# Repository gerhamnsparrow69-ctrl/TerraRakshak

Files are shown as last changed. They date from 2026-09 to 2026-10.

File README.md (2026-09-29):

# TerraRakshak
TerraRakshak: an AI-assisted 4WD mine rescue rover for SIH 2026 (SIH26039). Three-tier modular design with a 12V drivetrain, a 6-sensor MQ gas array, thermal and night-vision perception, and RPLIDAR SLAM, all integrated on a Raspberry Pi 5 running ROS 2. Team MineCrafters.
TerraRakshak is a modular rover that enters underground mines ahead of rescue teams to report toxic gases, heat signatures and terrain in real time. Built by Team MineCrafters (Team ID 152475) for Smart India Hackathon 2026, problem statement SIH26039.

Architecture

Tier 1, power and drivetrain: 12V LiPo, 2x BTS7960 drivers, 4 encoders and an Arduino Nano, with isolated 12V and 5V buses.
Tier 2, gas array: MQ-2, MQ-4, MQ-7, MQ-8, MQ-135 and MQ-136 sensors on an Arduino Nano, powered through a star topology.
Tier 3, compute and vision: Raspberry Pi 5 as the ROS 2 master, an ESP32 with 4x MLX90640 thermal arrays, 4x night-vision cameras, an RPLIDAR A1M8 and a DHT22.

Repo contents: mechanical design (chassis, machining, assembly sequence), electrical wiring and GPIO maps, and software.

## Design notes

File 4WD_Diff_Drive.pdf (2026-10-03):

SIH 2026 · Team MineCrafters (ID 152475) · Mine Rescue Rover · 4WD drivetrain (Part 4) · all dimensions in mm | Page 1

# Mine Rescue Rover · 4WD Drivetrain (under the base plate)

Four identical corner units (mirrored left/right): wheel -> machined hex drive adaptor -> 10 mm steel stub axle -> 3D-printed bearing flange (2 bearings) -> 3D-printed coupler -> 36 mm planetary gear motor with a built-in rear hall encoder, held in a 3D-printed U-bracket. Axles run parallel to the 30 cm side on Y = 90 (front) and Y = 310 (rear). The two motors of each side run in parallel on one BTS7960 driver (skid steer). The encoders feed the Tier 1 Nano (sheet 8), which closes the speed loop and sends wheel odometry to the Pi 5 alongside the LIDAR SLAM. Every dimension below comes from one model that is checked by script (sheet 6: 0 failures).

## Power

The rover carries three batteries: the 12 V LiPo (motors, through the two BTS7960 drivers), Battery B 5 V (Tier 1 Nano, the four encoders and the driver logic, plus the Tier 2 and Tier 3 logic) and Battery C 5 V (Raspberry Pi 5 and USB hub only, Part 2 sheet C). Battery C feeds nothing in the drivetrain, so the drivetrain sheets and the Tier 1 wiring sheet show only the 12 V LiPo and Battery B.

# Design summary

# | Item | Specification | Reason

1 | Motor | NFP-36GP-555-EN 12 V 27:1, 220 rpm no-load, 12.5 kg·cm rated, 8 mm D-shaft; 17 PPR AB hall encoder built into the motor rear. Body 104.5 (gearbox 34.5 + motor 57 + encoder 13) | Encoder in the same housing: wheel odometry and a closed speed loop with no extra parts to mount
2 | Corner layout | Motor face X 38, encoder rear X 142.5: 15 mm between opposite encoders | Two 104.5 motors fit face to face across the 300 mm plate with room for the encoder plugs
3 | Bearing flange | Top plate 45 (X -15 to 30); web and boss 15 mm outside the plate edge; 2 gussets 30 x 54.5 under the plate; bolts at X 8 / 22 | Carries the wheel load into 4 bolts; puts the bearings outboard so the motors fit
4 | Axle stack | Rod 47 = 15 adaptor / 1 shim / 15 bearings / 1 shim / 15 coupler | 15 mm engagement each side; shims keep spinning parts off the printed flange
5 | Motor mount | U-bracket cradle + clamp cap hold the motor along 60 mm | No cantilever and no holes under the batteries
6 | Wheel | 1/10 MT wheel Ø134.5 x 67, 12 mm hex (2.8" monster-truck set), soft-compound tyre, open-cell foam insert | Axle Z 67.25; lowest point 45.15 (42.15 loaded) for rubble. The tyre squashes ~3 mm and absorbs shock before it reaches the gearbox
7 | Damping | 1.5 mm neoprene pad (60 Shore A) under the flange AND under the bracket lips; both printed 1.5 mm shorter | Damps vibration. Both get a pad so the axle and motor stay exactly coaxial
8 | Fasteners | M4x20 countersunk (DIN 7991), heads flush in the plate top | Nothing pokes up under Battery C, the regulator or the Tier 1 mat
9 | Alignment | Bracket lips have ±5 mm slots; plate holes drilled at the slot centres after alignment | Build independent of small motor tolerances (match-drill)
10 | Cable exits | Ø12 grommets at (150, 115), (150, 285) for the motor leads; Ø10 at (150, 65), (150, 335) for the encoder cables | Keeps the 5 V encoder signals away from the PWM motor leads
11 | Track | Track 431, overall width 498; wheelbase 220, wheelbase/track 0.51 | Easy skid-steer turns and good roll stability on rubble
12 | Odometry | 1836 counts per wheel turn (4.55 counts/mm); per-side speed loop, stall cut-out, slip and encoder-fault detection (sheet 8) | Straight driving under uneven load, protection for gearboxes and printed parts, better SLAM

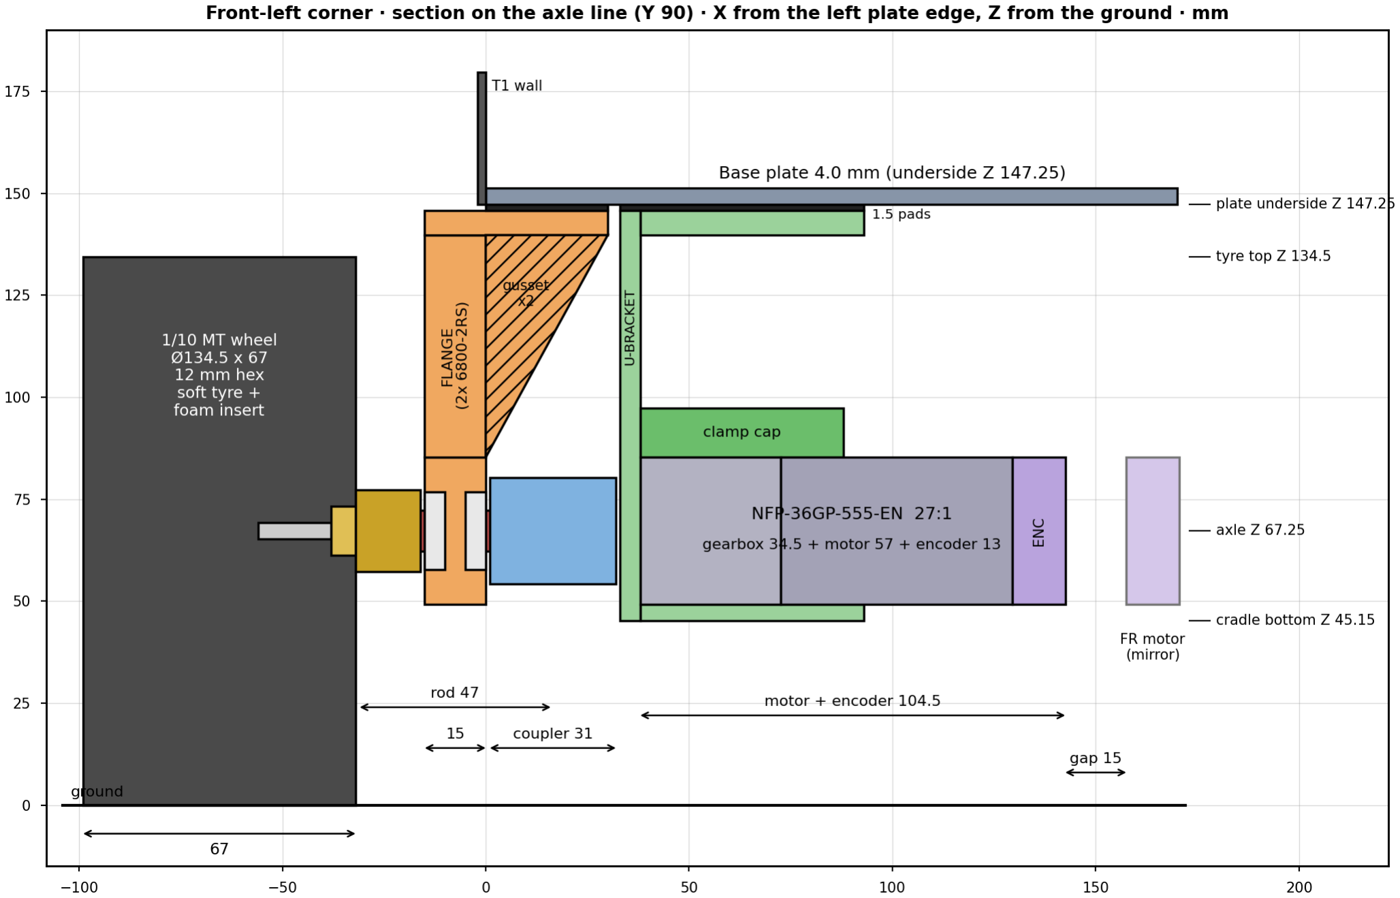
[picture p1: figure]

SIH 2026 · Team MineCrafters (ID 152475) · Mine Rescue Rover · 4WD drivetrain (Part 4) · all dimensions in mm | Page 2

# Sheet 1 · Corner geometry

Part | X from - to (left corner; right = 300 - X) | Z / section
Wheel (tyre) | -99.0 to -32.0 | Ø134.5 x 67, centre Z 67.25, top Z 134.5 (12.75 below the plate)
Hex adaptor | stud -56 to -38 · hex -38 to -32 · collar -32 to -16 | collar Ø20, hex 12 A/F
Shim (outer) | -16 to -15 | 10 x 14 x 1 steel shim, rides on the bearing inner race
Flange boss | -15 to 0 (15 outside the plate; inner face flush with the plate edge) | Ø36, 2 x 6800-2RS
Flange top plate | -15 to 30, Y ±30 about the axle; bolts X 8 / 22 | 6 thick, Z 139.75-145.75; pad X 0-30 only, Z 145.75-147.25
Flange gussets (2) | 0 to 30 (under the plate) | 5 thick at Y ±10 to ±15 about the axle, Z 85.25-139.75
Shim (inner) | 0 to 1
Stub axle | -31 to 16 | Ø10 x 47
Coupler | 1 to 32 | Ø26
U-bracket front wall | 33 to 38 | shaft hole Ø14
U-bracket cradle / lips | 33 to 93 | lips Y ±23.1 to ±43.1 about the axle, Z 139.75-145.75, pad above
Gearbox / can / encoder | 38 to 72.5 / 72.5 to 129.5 / 129.5 to 142.5 | Ø36, Z 49.25-85.25
Clamp cap | 38 to 88 | Z 85.35-97.35
Gap to the opposite motor | 142.5 to 157.5 | 15 mm: room for the encoder plugs (sheet 5, step 5)

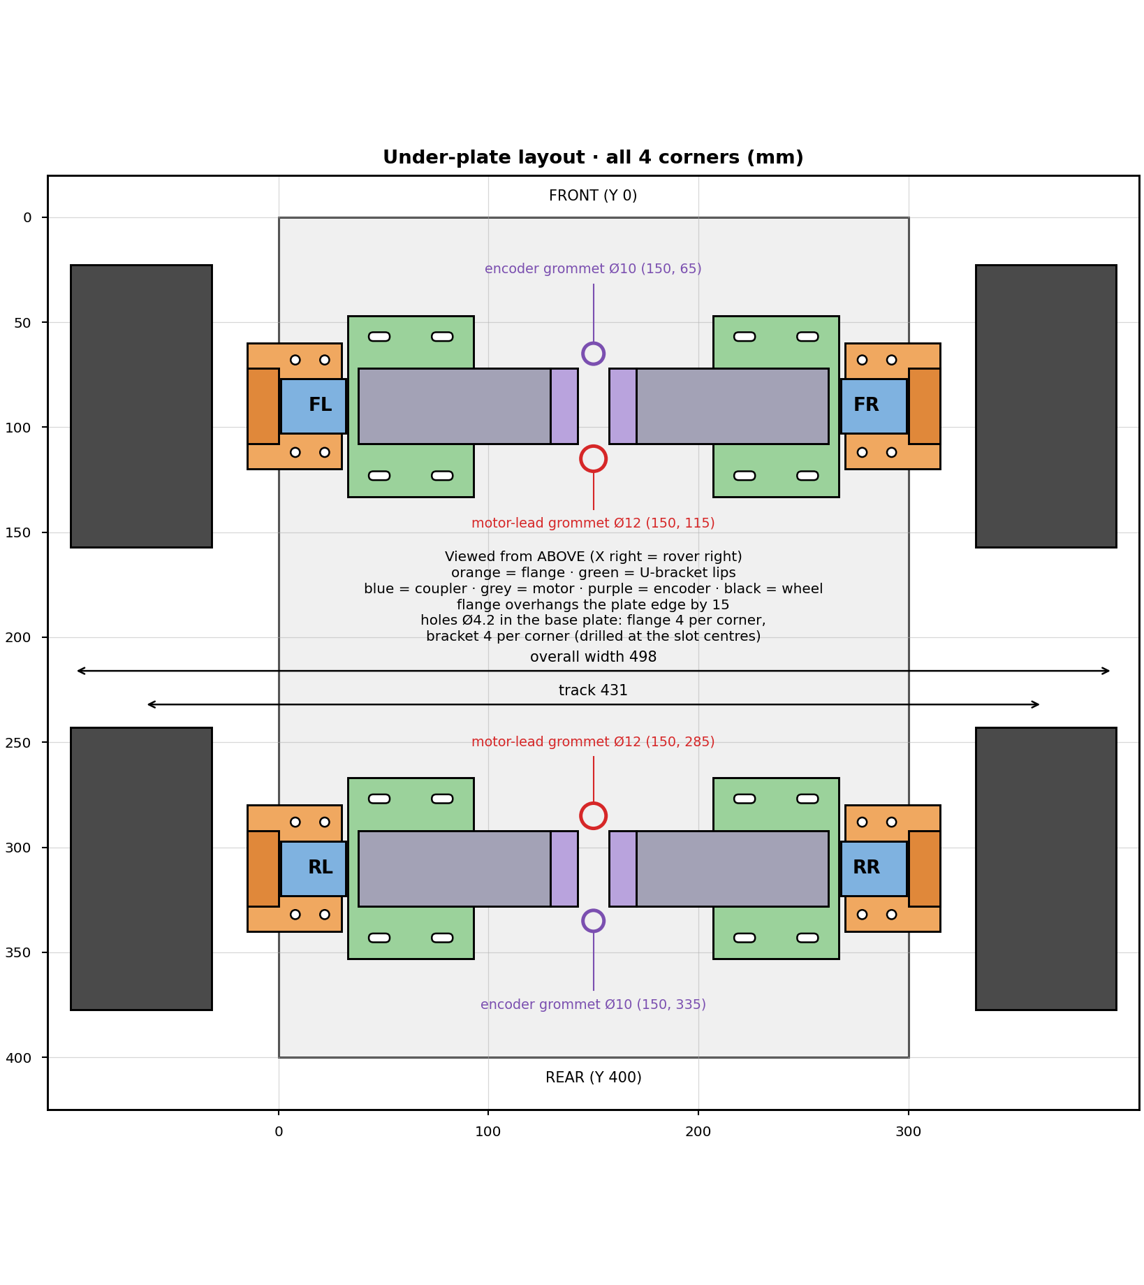
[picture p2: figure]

SIH 2026 · Team MineCrafters (ID 152475) · Mine Rescue Rover · 4WD drivetrain (Part 4) · all dimensions in mm | Page 3

# Sheet 2 · Under-plate layout

Base plate holes per corner (left front shown; right X -> 300 - X, rear Y -> 400 - Y): flange 4 x Ø4.2 with 90° countersink to Ø8.5 on the TOP face, at X 8 and 22, Y 68 and 112. Bracket 4 x Ø4.2 (same countersink) at the slot centres, nominal X 48 and 78, Y 56.9 and 123.1, drilled after the alignment step (sheet 5, step 6). Grommets: Ø12 at (150, 115) and (150, 285) for the motor leads; Ø10 at (150,
65) and (150, 335) for the encoder cables.

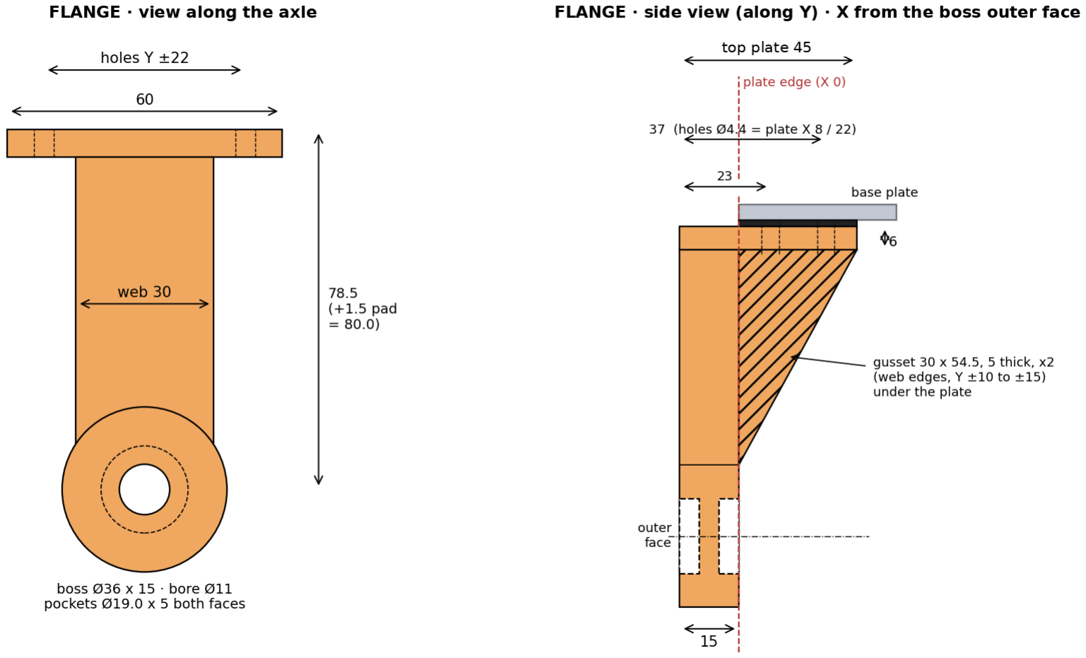
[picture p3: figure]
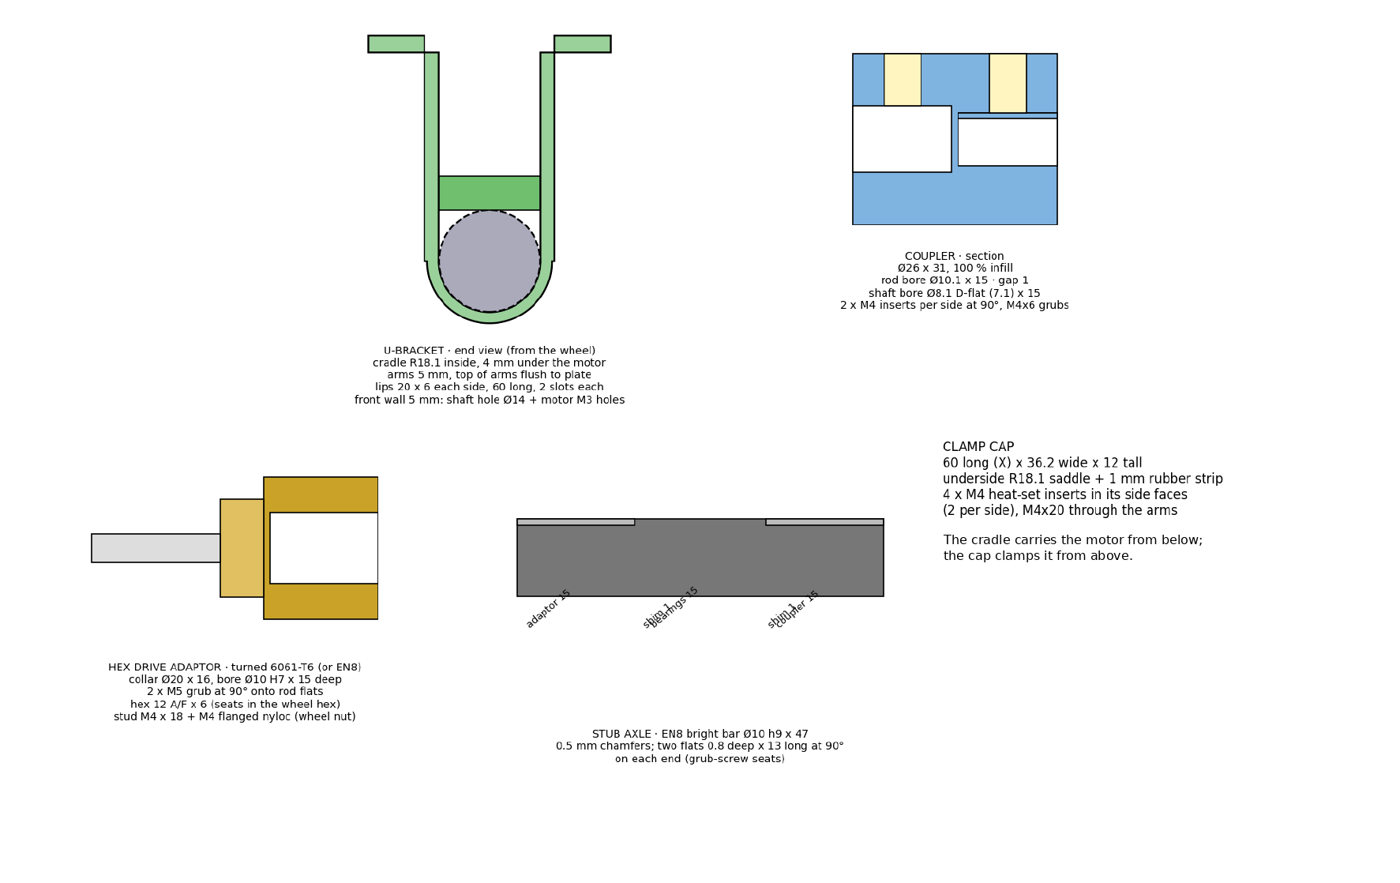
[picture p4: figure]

SIH 2026 · Team MineCrafters (ID 152475) · Mine Rescue Rover · 4WD drivetrain (Part 4) · all dimensions in mm | Page 4

# Sheet 3 · Parts

Printed: flange, U-bracket, clamp cap and coupler (4 of each). Machined: stub axle and hex drive adaptor (4 of each). The flange top plate is 45 long so the web and boss hang 15 mm outside the plate edge; the two gussets sit under the plate and carry the overhang into the bolts.

## U-bracket, coupler, clamp cap, hex drive adaptor and stub axle

## 3D-printing settings

Part | Qty | Material | Orientation on the bed | Settings
Flange | 4 | PETG (upgrade: PA6-CF or PETG-CF, hardened nozzle) | Outer boss face down: web, boss and gussets print as in-plane layers, bearing pockets print as true circles; the 45 mm top plate stands vertical | 0.4 nozzle, 0.2 layer, 6 walls, 6 top / 6 bottom, 60 % gyroid, 240 °C / bed 80 °C, supports only under the top-plate bolt holes. About 60 g each
U-bracket | 4 | same | Front wall down: every layer is the full U profile, so arm bending stays in-plane | same, 60 % gyroid, slots printed
Clamp cap | 4 | same | Flat top down | 5 walls, 40 % gyroid; press 4 M4 heat-set inserts after printing
Coupler | 4 | PETG or PA6-CF | Axis vertical, rod bore up | 100 % infill (rectilinear), 0.15 layer; 4 M4 heat-set inserts
Test ring | 1 | same | flat | Print a Ø19.0 pocket ring first: the bearing must press in by hand-vise. If loose, retain with Loctite 641 (or thin CA)

Printed holes are drawn at 4.4 mm (not 4.2) because printed holes shrink about 0.2 mm; drill to 4.2-4.4 if tight. Metal plate holes stay 4.2 mm.

SIH 2026 · Team MineCrafters (ID 152475) · Mine Rescue Rover · 4WD drivetrain (Part 4) · all dimensions in mm | Page 5

# Sheet 4 · Procurement (for 4 corners)

Item | Exact part | Qty | Note
Motor | NFP-36GP-555-EN 12 V, 27:1 (gearbox 34.5 mm), built-in 17 PPR AB hall encoder, XH2.54 6-pin cable, Ø8 D-shaft. Same size alternative: CHIHAI CHP-36GP-555-ABHLL 27:1 | 4 | About US$43 each. Ask for the outline drawing: body (gearbox face to encoder cover) must be 104.5 (max 106). Shaft extension 17-21 mm; cut to 21 if longer. Match-drill the M3 face holes
Wheels | 1/10 MT 2.8" wheel + tyre, 12 mm hex, Ø134.5 x 67, pre-glued, e.g. Jetko Rockform JK2803CB (ships with 12 / 14 / 17 mm hexes) | 4 | Fit the 12 mm hex. Soft compound with an open-cell foam insert; no closed-cell or dual-stage hard inserts. Check the M4 wheel stud takes the full nyloc through the hub
Bearings | 6800-2RS, 10 x 19 x 5 | 8 | 2 per flange
Stub axles | EN8 (or C45) bright bar Ø10 h9, cut to 47 | 4 | Mill or file the grub flats (sheet 3)
Hex adaptors | Turned to the sheet 3 drawing, 6061-T6 or EN8 | 4 | Any local lathe shop; bore Ø10 H7
Pads | Neoprene (CR) sheet 1.5 mm, 60 Shore A | 4 + 8 | 60 x 30 under each flange, 60 x 20 under each bracket lip; holes Ø4.5
Shims | 10 x 14 x 1 steel shim washers | 8
Bolts | M4 x 20 countersunk DIN 7991 + 1 mm rubber washers + M4 nyloc | 32 sets | 16 flange + 16 bracket lip, heads flush with the plate top
Cap bolts | M4 x 20 socket head | 16 | Into the cap inserts, no nut
Heat-set inserts | M4, 5.6-5.7 mm OD, 8 mm long (cap) / 6.4 mm (coupler) | 16 + 16
Grub screws | M4 x 6 (coupler) · M5 x 6 (adaptor), cup point | 16 · 8 | Loctite 243
Wheel nuts | M4 flanged nyloc | 4
Motor screws | M3, length = bracket wall 5 + thread depth in gearbox (usually 3-4) -> M3 x 8 | 16-24
Grommets | Rubber, 12 mm hole | 2 | Motor leads, (150, 115) and (150, 285)
Grommets | Rubber, 10 mm hole | 2 | Encoder cables, (150, 65) and (150, 335)
Encoder wiring | 4-core 24 AWG flexible cable (or 4 twisted wires) + JST XH2.54 6-pin pigtail if the motor cable is short; Dupont or screw terminals at the Nano | 4 x ~50 cm | Heat-shrink every joint; label FL / RL / FR / RR at both ends
Filament | PETG (or PA6-CF / PETG-CF) | ~1 kg | All printed parts and the test ring

SIH 2026 · Team MineCrafters (ID 152475) · Mine Rescue Rover · 4WD drivetrain (Part 4) · all dimensions in mm | Page 6

# Sheet 5 · Assembly (base plate upside down on the bench)

## 1 · Prepare

Print the flanges, U-brackets, clamp caps, couplers and the test ring. Press the heat-set inserts. Cut and flat the axles. Deburr. Drill the flange holes and the four grommet holes in the base plate (sheet 2); leave the bracket holes for step 6.

## 2 · Flanges

Press two 6800-2RS into each flange (one per face, flush). Lay the 1.5 mm pad (60 x 30) where the top plate meets the base plate (X 0-30), then bolt: countersunk head flush in the plate top, plate, pad, flange, rubber washer, nyloc. Tighten until the pad just starts to bulge (do not crush it). The boss hangs outside the plate: its inner face is flush with the plate edge, the outer face is 15 mm out.

## 3 · Axles

Slide the outer shim, then the axle through the bearings from outside, so 15 mm protrudes outboard beyond the shim and 16 mm inboard. Fit the inner shim.

## 4 · Couplers

Push the coupler rod bore fully onto the inner 15 mm of the axle, against the inner shim (the shims should turn freely, with no end play). Tighten both grubs onto the flats (Loctite 243).

## 5 · Motors and encoder socket

Find the encoder socket on the motor rear. Radial socket: turn the motor so it points toward the nearest plate end (front motors to the front, rear motors to the rear), i.e. toward the encoder grommet. Axial socket (on the back face): left motors socket at 12 o'clock, right motors at 6 o'clock, so the two plugs in the 15 mm gap never face each other. The M3 face holes are match-drilled, so any rotation works. Then screw the face to the U-bracket wall (M3), lay the motor in the cradle with the rubber strip, fit the clamp cap and its 4 bolts.

## 6 · Align and drill (match-drill)

Slide the motor shaft into the coupler until the bracket lips sit flat on the plate and the wall is 1 mm from the coupler end. Mark the plate through the 4 slot centres (nominal X 48 / 78), remove the motor, drill Ø4.2 and countersink the top, then refit with the lip pads and bolt (same stack and pad squeeze as the flange). Tighten the coupler shaft grubs onto the D-flat. Turn the wheel end by hand: it must turn with no binding.

## 7 · Wheels

Fit the 12 mm hex in each wheel (the set also ships 14 and 17 mm hexes). Slide the hex adaptor onto the outer 15 mm (against the outer shim), tighten both M5 grubs onto the flats (Loctite 243), fit the wheel onto the hex and tighten the M4 flanged nyloc.

## 8 · Wiring

Motor leads up through the Ø12 grommets: FL + RL to the LEFT driver M+ / M-, FR + RR to the RIGHT driver (Part 1). Encoder cables up through the Ø10 grommets to the Tier 1 Nano (sheet 8). If the motor's 6-pin plug also carries M+ / M-, split it at the motor: those two go to the driver on 18 AWG, only the four encoder wires go to the Nano. Zip-tie the cables to the lips, clear of the tyres. Do not swap M+ / M- to fix direction: the bring-up check stores the signs in the Nano.

## 9 · Check

On the floor the tyres squash about 3 mm; lowest point (cradle) about 42.2 mm; 15 mm between opposite encoder covers. Then run the bring-up check (sheet 8, step 3) with the wheels off the ground.

SIH 2026 · Team MineCrafters (ID 152475) · Mine Rescue Rover · 4WD drivetrain (Part 4) · all dimensions in mm | Page 7

# Sheet 6 · Verification

| Check (script: drivetrain_model.py)
OK | Flange/bracket drop plate-underside to axle = 80.0 mm (spec 80.0)
OK | Axle height = tyre radius = 67.25 mm
OK | Tyre top 134.5, plate underside 147.25 -> clearance 12.75 mm
OK | Rod 47 mm = adaptor 15 + shim 1 + bearings 15 + shim 1 + coupler 15
OK | Coupler end 32.0, bracket wall starts 33.0 (gap 1.0)
OK | Motor shaft engagement in coupler 15.0 mm (min 12)
OK | Coupler clears flange boss (shim 1.0 mm between)
OK | Motor body = gearbox 34.5 + can 57 + encoder 13 = 104.5 mm
OK | Left motor rear 142.5, right motor rear 157.5 -> gap 15.0 mm (>= 12 for an axial encoder socket)
OK | Flange top plate ends X 30, bracket lips start X 33 (gap 3.0)
OK | Flange top plate X -15 to 30: 15 mm overhang past the plate edge, bolts stay at X 8 / 22
OK | Gussets (under the plate) clear the coupler top Z 80.25 by >= 6.8 mm
OK | Gusset ends X 30, U-bracket wall starts X 33 (gap 3.0)
OK | With 3 mm soft-tyre squash under load: lowest point 42.15 mm
OK | Lowest point (bracket cradle) 45.15 mm above ground; motor + encoder 49.25; flange boss 49.25
OK | Tyre inner face at X -32.0 -> 17.0 mm to the flange boss, 32 mm outside the plate edge
OK | Track (tyre centre to centre) 431 mm, overall width 498 mm
OK | Tyres along Y: front 22.75-157.25, rear 242.75-377.25 -> inside the plate length, 85.5 mm apart
OK | M4x20 countersunk flange (CSK flush) + 1.5 pad: plate 4 + pad 1.5 + part 6 + rubber washer 1 + nyloc 5 -> 2.5 mm past nut
OK | M4x20 countersunk bracket lip (CSK flush) + 1.5 pad: plate 4 + pad 1.5 + part 6 + rubber washer 1 + nyloc 5 -> 2.5 mm past nut
OK | Pads: flange and bracket lips both on 1.5 mm pads, both printed 1.5 mm shorter -> axle and motor coaxial at 80.0 below the plate
OK | M4x20 arm into cap insert: 14.2 mm of thread in the cap
OK | Under-plate footprints: flange top, bracket lips, 4 grommets - no overlaps
OK | Encoder grommet (150, 65): its edge is 2 mm off the motor side in plan and 62 mm above the motor top
OK | Motor cantilever past the cradle: 49.5 mm, carried by the clamp cap
OK | Encoder: 17 PPR x 27:1 x 4 = 1836 counts per wheel turn = 4.55 counts/mm (loaded tyre Ø128.5)
OK | Worst-case edge rate, 4 motors at no-load 220 rpm: 26.9 k interrupts/s (~5 µs each -> 13 % of the Nano)
| TOTAL FAILURES: 0

## Confirm on the real parts

# | Check

1 | Motor shaft extension (face to tip) is 17-21 mm; cut to 21 if longer. With 21 the coupler takes 15 mm of shaft.
2 | Motor body length (gearbox face to the back of the encoder cover, socket not included) is 104.5, at most 106. Above 106 the gap between opposite motors drops below 12 mm. Measure one motor before printing the flanges.
3 | Encoder socket: if it is axial, plug + wire bend must stick out 11 mm or less from the cover (sheet 5, step 5 staggers the plugs).
4 | Encoder pinout from the motor label / datasheet: which wires are M+, M-, GND, VCC, A, B. VCC takes 3.3-5 V only, never 12 V.
5 | Chassis doc: nothing hangs under the plate where the bracket lips sit (X 33-93 and 207-267, Y 46.9-133.1 and 266.9-353.1), in particular no lower-T1-bracket nut or bolt tip, and nothing hangs below the plate edge at the flange overhang (X -15 to 0).
6 | Tier 1 layout above: the Ø10 holes at (150, 65) and (150, 335) and the bracket holes at X 48 / 78 are clear of everything on the plate top (standoffs, pillars, battery bays).
7 | Wheel: 12 mm hex seat; the tyre inner face ends up 32 mm outside the plate edge, and the M4 stud still takes the full nyloc through the wheel hub.
8 | Bearing pocket press fit on the test ring before printing all four flanges.
9 | After fitting the pads, the axle and motor turn freely by hand; if the coupler binds, the two pads are squeezed unequally.

SIH 2026 · Team MineCrafters (ID 152475) · Mine Rescue Rover · 4WD drivetrain (Part 4) · all dimensions in mm | Page 8

# Sheet 7 · Insulation mat (chassis, all decks)

A mat on every enclosed deck floor keeps loose wires, solder joints and bolt tips off the aluminium. It goes inside each deck only, not on the exposed ledges of the lower roofs and not on the top roof.

Item | Specification
Material | Silicone rubber sheet, 1.5 mm, 50 Shore A, flame-retardant grade (UL94 V-0), rated to 200 °C. Silicone survives the heat near the BTS7960 heatsinks and does not melt onto the plate
Tier 1 | 30.0 x 40.0 cm on the base plate
Tier 2 | 22.0 x 35.0 cm on the mid plate, inside the Tier 2 box
Tier 3 | 18.1 x 31.1 cm on the Tier 2 roof, inside the Tier 3 box
Cut-outs (+1 mm all round) | Pillars, every lip / lower bracket, latch posts and the wire pass-through holes: brackets must clamp metal to metal, never on the mat. This includes Ø14 cut-outs around the four drivetrain grommets at (150, 65), (150, 115), (150, 285) and (150, 335)
Cut-outs under breadboards | All 400-pt and 170-pt breadboards stick straight onto the aluminium (their adhesive will not hold on silicone). This keeps the MQ and MLX90640 heights, so the gas ports (4.40 cm) and thermal arches (3.5 cm) still line up
Holes | Punch Ø5 for every bolt and standoff that passes through the floor (drivers, bus bars, Pi 5, hub, battery bays)
Fixing | Held down by the parts bolted through it; add a few dots of neutral-cure RTV silicone at the corners
Height effect | Parts sitting on the mat rise 1.5 mm. The tallest (Tier 1 drivers, 4.5 cm) become 4.65 cm, still 2.8 cm below the nearest bolt tip hanging from the mid plate (7.42 cm). All drivetrain bolt heads are countersunk flush, so nothing pushes up under the mat

Quantity: one 50 x 50 cm sheet covers Tier 1; one more sheet covers Tier 2 and Tier 3.

SIH 2026 · Team MineCrafters (ID 152475) · Mine Rescue Rover · 4WD drivetrain (Part 4) · all dimensions in mm | Page 9

# Sheet 8 · Encoders and the Tier 1 Nano

Each motor carries a 2-channel hall encoder: 17 pulses per motor turn on A and B, 90° apart. Through the 27:1 gearbox with x4 decoding that is 1836 counts per wheel turn, 4.55 counts per mm (loaded tyre Ø128.5). The Tier 1 Nano counts all four, runs a 50 Hz speed loop per side (the two motors of a side share one BTS7960) and streams the counts to the Pi 5 at 25 Hz. Worst case (all four at 220 rpm no-load) is 26.9 k edges/s, well inside the Nano's interrupt budget.

## Encoder cable (per motor)

Encoder wire | Goes to | Note
VCC | Tier 1 5 V rail (Battery B) | 3.3-5 V only. The encoder has its own pull-ups, so A / B swing 0-5 V
GND | Tier 1 GND trunk | No extra link to the 12 V side (one common GND link rule, Part 2 sheet C)
A, B | Nano pins in the table below | Keep these 4 wires together, away from the motor leads
M+, M- (if on the plug) | BTS7960 M+ / M- of that side, 18 AWG | Split at the motor, through the Ø12 grommet (sheet 5, step 8)

Only two of the rover's three batteries reach Tier 1 drivetrain circuits: the 12 V LiPo (driver B+ / B-) and Battery B (5 V rail). Battery C feeds only the Pi 5 and the USB hub (Part 2 sheet C).

## Tier 1 Nano pin map

Nano pin | Connects to | Why
D9 / D10 | LEFT BTS7960 RPWM / LPWM | Timer1 PWM, 3.92 kHz (driver limit 25 kHz)
D8 | LEFT BTS7960 R_EN + L_EN (tied) | HIGH = enabled; LOW while booting
D3 / D11 | RIGHT BTS7960 RPWM / LPWM | Timer2 PWM, same 3.92 kHz
D12 | RIGHT BTS7960 R_EN + L_EN (tied)
D4 / D5 | FL encoder A / B | Port D pin-change interrupt (fixed pins)
D6 / D7 | RL encoder A / B | Port D pin-change interrupt (fixed pins)
A0 / A1 | FR encoder A / B | Port C pin-change interrupt (fixed pins)
A2 / A3 | RR encoder A / B | Port C pin-change interrupt (fixed pins)
D13 | on-board LED | slow blink running · solid waiting for the Pi · fast blink fault
5V / GND | Tier 1 5 V rail: both drivers' VCC / GND and the 4 encoders' VCC / GND | Part 2 sheet C
USB (D0 / D1) | Pi 5 through the hub | 115200 baud; free pins: D2, A4, A5, A6, A7
Driver pins match the Part 1 wiring sheet. Driver pins can be changed in the constants at the top of the sketch (PWM must stay on D3 / D9 / D10 / D11). The encoder pins are fixed: the interrupt code reads whole ports. BTS7960 R_IS / L_IS stay unconnected; stalls are detected from the encoders.

## Link to the Pi 5 (full description in the sketch header)

Direction | Message | Meaning
Pi -> Nano | V,left,right | wheel speed per side, mm/s (±1000), closed loop
| P,left,right | open-loop PWM (±255), bring-up only
| S · R · I · D | brake · zero counters, clear faults · identify · dump config
| C,fl,rl,fr,rr,ml,mr · K,kp,ki,kff | signs (±1) · gains x1000, both saved in EEPROM
Nano -> Pi | E,ms,fl,rl,fr,rr,vl,vr,pl,pr,flags,errs* HH | 25 Hz: cumulative counts, side speeds, PWM, flags (stall, slip, encoder fault, watchdog), missed edges
| I,TIER1_DRIVE,4B,1.0 · A,x · N,reason | identity (at boot) · ack · reject

SIH 2026 · Team MineCrafters (ID 152475) · Mine Rescue Rover · 4WD drivetrain (Part 4) · all dimensions in mm | Page 10

## Built-in protection

Situation | What the Nano does
No command for 300 ms | Both sides ramp to 0 and brake (watchdog flag)
Stall: PWM ≥ 140 with the side below 15 mm/s for 0.7 s | That side is braked and latched until the Pi commands 0 for it (after 1 s) or sends R. Protects gearboxes, printed couplers and the 20 A fuse
Any speed change | Setpoint ramp 1200 mm/s²
One encoder dead (its partner turns, it does not) | Flag for that wheel; the side keeps running on the other wheel's encoder
Front and rear of one side differ (> 100 mm/s or 30 %) | Slip flag; the ROS 2 node widens the odometry covariance

## Bring-up and calibration

Step | Do this
1 | Flash tier1_drive_nano/tier1_drive_nano.ino (Arduino IDE, board Arduino Nano, ATmega328P; pick 'Old Bootloader' if the upload times out). The LED stays on: waiting for the Pi.
2 | On the Pi 5: python3 -m pip install pyserial, then ls /dev/serial/by-id/ to find the Tier 1 Nano (the Tier 2 Nano and the ESP32 are on USB too; always use the by-id path).
3 | Rover on blocks, wheels off the ground, 12 V on: python3 rover_base.py --port <path> --check. It spins each side slowly, asks whether the wheels turned forward, and stores the motor and encoder signs in the Nano. A reversed side is fixed in software.
4 | On the floor: --calib-distance 1000 (tape measure), then --calib-turn (one turn in place). Results go to ~/.config/rover_base.json. Skid steer usually calibrates to an effective track larger than 431.
5 | --monitor shows counts, speeds and flags. For the SLAM stack: python3 rover_base_ros2.py --ros-args -p port:=<path> (/cmd_vel in; /odom and the odom -> base_link TF out).

Simulation test (simulated Nano with motor, quadrature and driver models, driven by the Pi code): sign detection on deliberately mis-wired hardware, 300 mm/s tracking, straight and turning odometry, stall latch and release, slip, dead-encoder fallback, watchdog and config storage all passed. Final gains are tuned on the real rover with --gains.

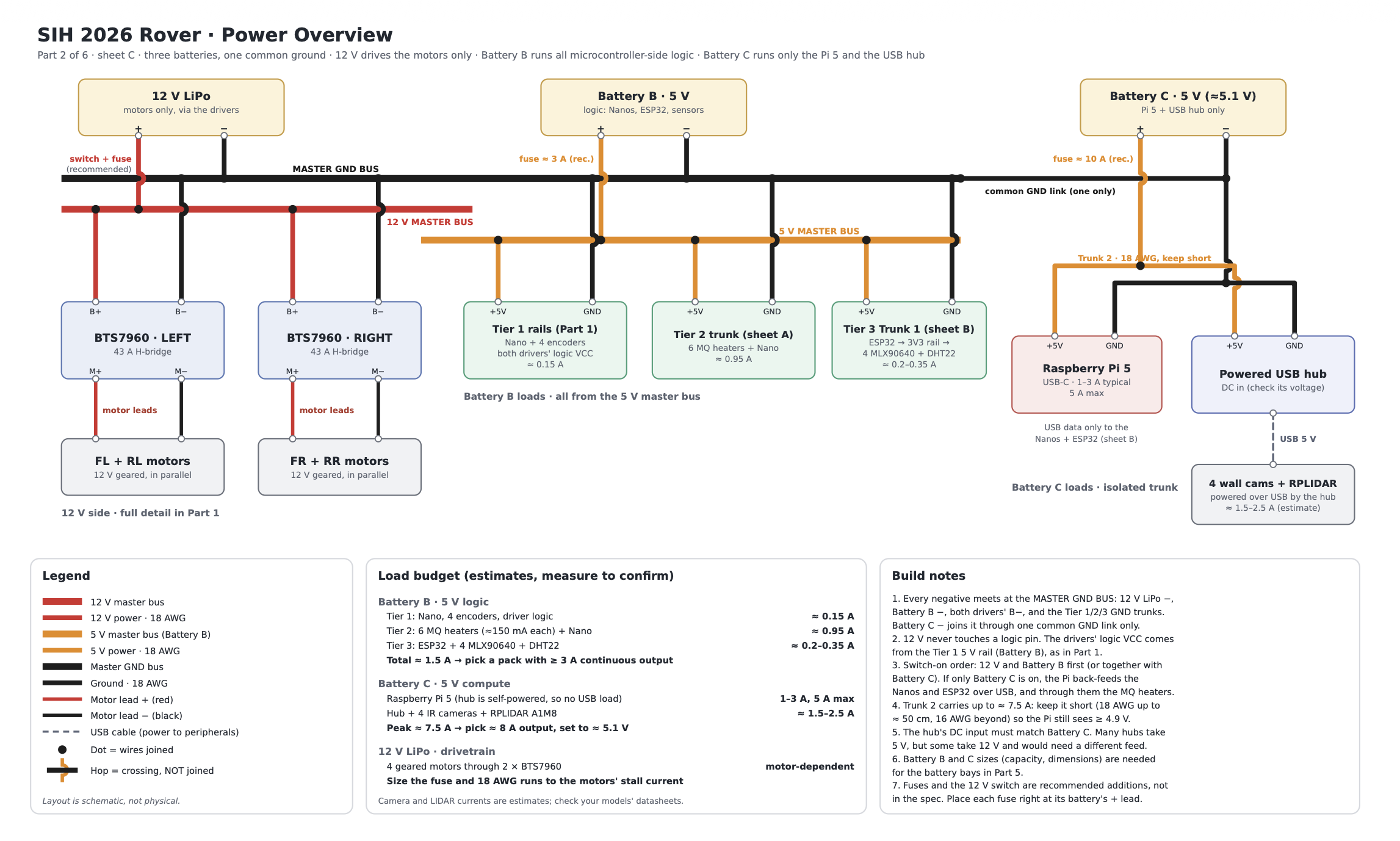
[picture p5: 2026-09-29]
Wiring/Power_overview.png

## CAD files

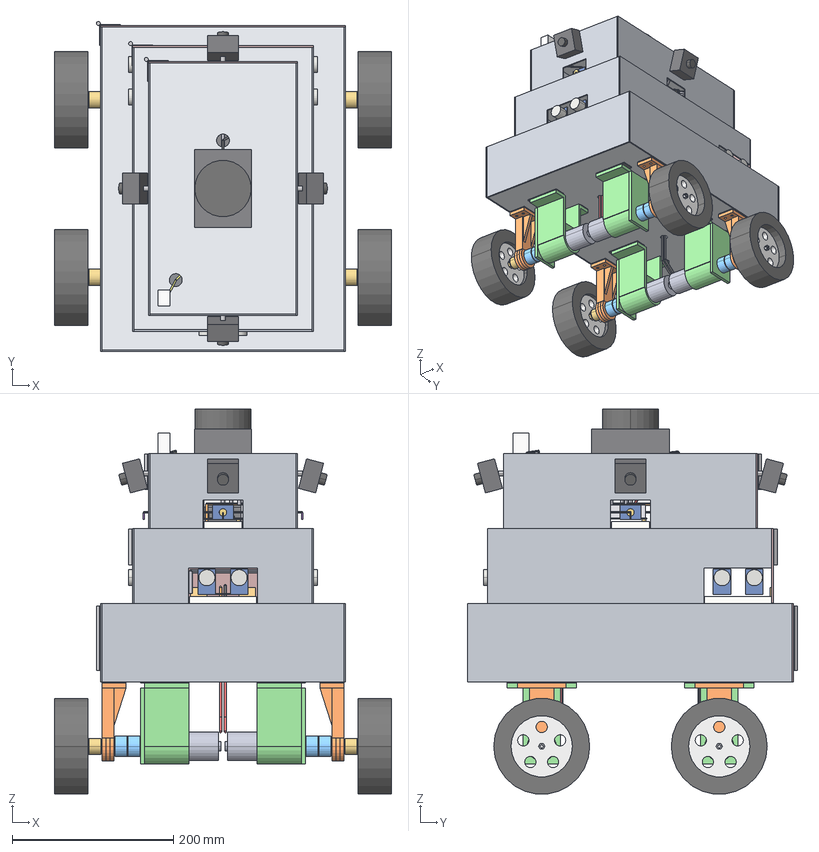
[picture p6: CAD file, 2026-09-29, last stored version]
SIH2026_Rover_Full_Assembly.step
418.0 x 409.0 x 477.1 mm
Base_Plate_4mm
Mid_Plate_3mm
Tier2_Roof_3mm
Roof_3mm
T1_Wall_Left
T1_Wall_Right
T1_Wall_Front
T1_Door_Rear
T2_Wall_Left
T2_Wall_Right
T2_Wall_Front
T2_Door_Rear
T3_Wall_Left
T3_Wall_Right
T3_Wall_Front
T3_Door_Rear
T1_Door_Hinge
T2_Door_Hinge
T3_Door_Hinge
T1_Corner_Pillars
T2_Latch_Post
T3_Latch_Post
T1_L_Brackets
T2_L_Brackets
T3_L_Brackets
T1_Silicone_Mat
T2_Silicone_Mat
T3_Silicone_Mat
Battery_12V_LiPo
Battery_B_Logic_5V
Battery_C_Pi_5V
Regulator_5V1_8A
Driver1_BTS7960
Driver2_BTS7960
Bus_12V
Bus_5V
Bus_GND
T1_Breadboard
T1_Arduino_Nano
T2_Board_Front
T2_Board_Centre
T2_Board_Left
T2_Board_Right
T2_Arduino_Nano
MQ_2
MQ_4
MQ_7
MQ_8
MQ_135
MQ_136
T3_Mini_Front
T3_Mini_Rear
T3_Mini_Left
T3_Mini_Right
T3_Breadboard_ESP32
ESP32_DevKit
MLX90640_Front
MLX90640_Rear
MLX90640_Left
MLX90640_Right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

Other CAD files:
SIH2026_Rover_Full_Assembly.f3d

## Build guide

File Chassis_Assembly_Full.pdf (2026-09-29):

SIH 2026 · Team MineCrafters (ID 152475) · Mine Rescue Rover · Chassis & electronics assembly (Part 3) · all dimensions in cm unless marked | Page 1

# Mine Rescue Rover · Chassis, Enclosures & Electronics Assembly

Tier 1 skeleton, Tier 2 gas deck, Tier 3 compute deck, roof, walls, doors, fasteners and component placement. The 4WD drivetrain under the base plate is a separate document (next part). Every placement in this document comes from one coordinate model that is checked by script for clashes, fit and bolt length (results on the last page: 0 errors).

# Key design decisions

# | Design adopted | Why

1 | M4x20 everywhere structural; stack: head · metal washer 0.8 mm · plate · bracket · 1.0 mm rubber washer · M4 nyloc (5.0 mm) | Lengths checked per joint (sheet 3)
2 | Walls outside every plate, zero gap. Bracket outer faces flush with the plate edge; plate sizes unchanged | Deck dimensions never change
3 | Walls cover the plate edges: Tier 1 = 9.7 (0.4 + 9.0 + 0.3), Tier 2/3 = 9.3 (9.0 + 0.3) | Full 9.0 cm clear height inside every tier
4 | Pillars tapped 20 mm (drill 3.3 mm to 23 mm). M4x20 through the 4 mm base engages 15.2 mm of thread | A 15 mm tap depth would bottom out and the bolt would not clamp
5 | Drill 4.2 mm clean through the pillar, washer + nyloc inside (stack 18.6 mm, 1.4 mm past nut). Side-wall holes Z 3.0/6.0, end-face holes Z 3.5/6.5 so they never cross | An M4x20 cannot be threaded into a 10 mm pillar side
6 | Rear wall of each tier = hinged access door: piano hinge at rear-left, 2 M4x20 latch bolts at rear-right (Tier 1 into the RR pillar, Tier 2/3 into a 45 mm latch post). Rear brackets stay as door stops | Hand access for lip bolts; no nuts needed inside a closed box
7 | Gas ports 8.5 x 4.40 cm, open at the bottom: MQ modules stand vertical (32 mm PCB) and their domes face out. Open bottom lets the box drop over the jutting sensors | Vertical sensors are 4.30 cm tall
8 | MLX90640 110° stands on its header facing the wall (a flat board looks at the ceiling). Arches 4.9 x 3.5 cm; left/right minis at Y 13.2-17.9 so all 4 lenses sit on the arch centres | Unclipped 110°x70° view; 4 x 110° = full 360° coverage
9 | Camera holes Z 6.80 | A camera at 5.75 would hang into the thermal sensor's upper field of view
10 | Battery C bay beside the 12 V bus (X 2.3-9.5, Y 2.3-15.5) + 5.1 V regulator bay (X 21.0-27.0, Y 11.0-15.5) | Pi 5 + hub isolated from logic power
11 | Real A1M8 envelope 7.03 x 9.68 x 5.5 at dead centre | Datasheet size

SIH 2026 · Team MineCrafters (ID 152475) · Mine Rescue Rover · Chassis & electronics assembly (Part 3) · all dimensions in cm unless marked | Page 2

# Sheet 1 · Components and exact sizes used

Item | Model chosen | Size used in the model (cm) | Notes
Gas sensors x6 | MQ-2/4/7/8/135/136 FC-22 style modules | PCB 3.2 x 2.2, envelope 3.2 x 2.2 x 2.7, dome Ø2.0 | Published module size 32x22x27 mm. Standing vertical on the 4-pin header
Thermal x4 | Adafruit MLX90640 4469 (110° x 70°) | 2.58 x 1.78 x 1.05 | Wide version chosen for maximum coverage; 3.3-5 V supply, runs on ESP32 3V3
400-pt breadboards x5 | standard | 8.2 x 5.5 x 0.85 | Fixed with their adhesive backing (no holes exist for standoffs)
170-pt minis x4 | standard | 4.7 x 3.5 x 0.85
USB hub | Waveshare USB-HUB-7U | reserved bay 11.8 x 7.5 x 3.0 | 7 x USB 2.0, MTT, DC 5 V terminal input only (matches Battery C), metal case with mounting holes. Check its outline drawing (Waveshare wiki, image only) against the bay before buying.
Battery C (Pi + hub) | 2S 7.4 V LiPo + 5.1 V step-down | bay 7.2 x 13.2 x 4.5; regulator bay 6.0 x 4.5 x 2.5 | Pack: 2S, 3000-4000 mAh, >=20C, case <= 13.0 x 7.0 x 4.5. Regulator: 5.1 V out, >=8 A continuous (Pi 5 up to ~5 A + hub 1.5-2.5 A). Pick a pack by its datasheet case size, not the listing photo
Raspberry Pi 5 | 8 GB | 8.5 x 5.6, 3.0 tall on 1.0 standoffs | M2.5 holes 58 x 49 mm, 3.5 mm from edges
RPLIDAR | Slamtec A1M8 | 9.68 x 7.03 x 5.5 | Mount through its own base holes; match-drill the roof from the unit
DHT22 | 3-pin module | 1.5 x 2.0 footprint, 2.51 tall | Roof front-left
Brackets | 20 x 20 x 2 mm aluminium angle, 20 mm wide | 2.0 x 2.0 x 2.0 | One Ø4.2 hole per leg at 11 mm from the corner
Pillars / latch posts | 10 x 10 mm solid aluminium | 1 x 1 x 9.0 / 1 x 1 x 4.5 | Tapped M4 20 mm deep at bolted ends
Hinge | aluminium piano hinge, 50 mm open (2 x 25 mm leaves) | cut to 8.0 (T1) / 4.4 (T2, T3) long | Knuckle on the outside rear-left corner

# Sheet 2 · Plate and wall cut list

Part | Qty | Size (cm) | Material | Machining
Base plate (Tier 1 floor) | 1 | 30.0 x 40.0 | 4.0 mm Al | 12 lower-bracket holes, 4 pillar holes (under pillars, bolt up), driver/bus/battery fixings, drivetrain pattern (separate doc)
Mid plate (T1 roof / T2 floor) | 1 | 30.0 x 40.0 | 3.0 mm Al | 12 upper-bracket + 4 pillar holes, 8 Tier-2 lip holes, hinge-side clearance, H-T2 Ø16 at (15.0, 26.2), H-T3 Ø25 at (22.0, 25.7)
Tier 2 roof (T3 floor) | 1 | 22.0 x 35.0 | 3.0 mm Al | 8 roof-bracket holes, latch-post hole, 8 Tier-3 lip holes, H-T3 Ø25 at T2-local (18.0, 23.2)
Roof | 1 | 18.1 x 31.1 | 3.0 mm Al | 8 roof-bracket holes, latch-post hole, H-DHT22 Ø16 at (3.2, 4.2), H-LIDAR Ø16 at (9.05, 21.5), LIDAR holes match-drilled
T1 left / right side walls | 2 | 40.2 x 9.7 | 2.0 mm Al | Front end overlaps front wall; rear end flush with plate edge (door covers it)
T1 front wall | 1 | 30.0 x 9.7 | 2.0 mm Al | Sits between the side walls
T1 rear door | 1 | 30.4 x 9.7 | 2.0 mm Al | Covers side-wall ends
T2 side walls | 2 | 35.2 x 9.3 | 2.0 mm Al | MQ ports Y 26.6-35.0 x 0-4.40
T2 front wall | 1 | 22.0 x 9.3 | 2.0 mm Al | MQ port X 6.75-15.25 x 0-4.40
T2 rear door | 1 | 22.4 x 9.25 | 2.0 mm Al | Solid; 0.5 mm above the floor so it swings
T3 side walls | 2 | 31.3 x 9.3 | 2.0 mm Al | Arch Y 13.1-18.0 x 0-3.5, camera hole (15.55, Z 6.8)
T3 front wall | 1 | 18.1 x 9.3 | 2.0 mm Al | Arch X 6.6-11.5 x 0-3.5, camera hole (9.05, Z 6.8)
T3 rear door | 1 | 18.5 x 9.25 | 2.0 mm Al | Arch + camera hole as front (shifted +0.2 by the overlap)
Pillars | 4 | 1 x 1 x 9.0 | 10 mm Al bar | Ends tapped M4 x 20 deep; 2 through-holes per outer face (see #5)
Latch posts | 2 | 1 x 1 x 4.5 | 10 mm Al bar | Top tapped 20 deep; door taps (Y) at Z 4.9 and 6.5; side through-hole (X) at Z 5.7
L-brackets | 24 (T1) + 16 (T2) + 16 (T3) | 20 x 20 x 20 mm | 2.0 mm Al | T1 12 lower + 12 upper; T2/T3 8 lips + 8 roof brackets each (2 per wall)

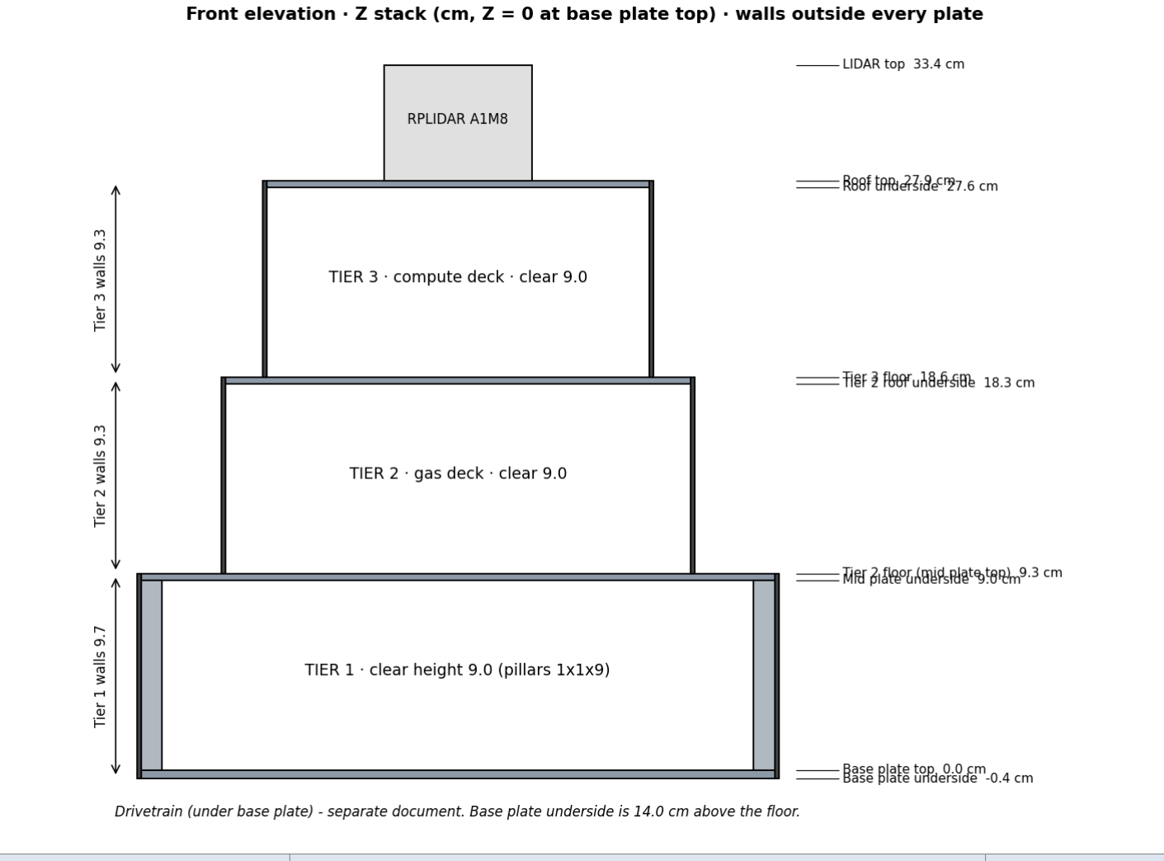
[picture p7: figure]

SIH 2026 · Team MineCrafters (ID 152475) · Mine Rescue Rover · Chassis & electronics assembly (Part 3) · all dimensions in cm unless marked | Page 3

# Sheet 3 · Heights and fasteners

Joint | Stack (mm) | Past the nyloc
Bracket to 3.0 mm plate | washer 0.8 + plate 3.0 + bracket 2.0 + rubber 1.0 + nyloc 5.0 = 11.8 | 8.2 mm
Bracket to 4.0 mm base plate | 0.8 + 4.0 + 2.0 + 1.0 + 5.0 = 12.8 | 7.2 mm
Wall to bracket leg | 0.8 + wall 2.0 + bracket 2.0 + 1.0 + 5.0 = 10.8 | 9.2 mm (points inward, all checked clear)
Wall to pillar / latch post (through) | 0.8 + 2.0 + 10.0 + washer 0.8 + nyloc 5.0 = 18.6 | 1.4 mm (2 threads, enough for the nylon insert)
Plate into pillar end (tapped) | 0.8 + 4.0 (base) or 3.0 (mid) -> 15.2 / 16.2 mm of thread | tap depth 20 mm, Loctite blue
Door into pillar / post (tapped) | 0.8 + door 2.0 -> 17.2 mm, exits 7.2 mm inside the corner | corner area is clear
Hinge leaf to wall | 0.8 + leaf 1.0 + wall 2.0 + 0.8 + 5.0 = 9.6 | 10.4 mm

Rubber washers go only where a bolt passes an L-bracket (spec 7.2). Every lip bolt tip that hangs into the deck below stops 1.58 cm under that plate; the script confirms nothing sits there.

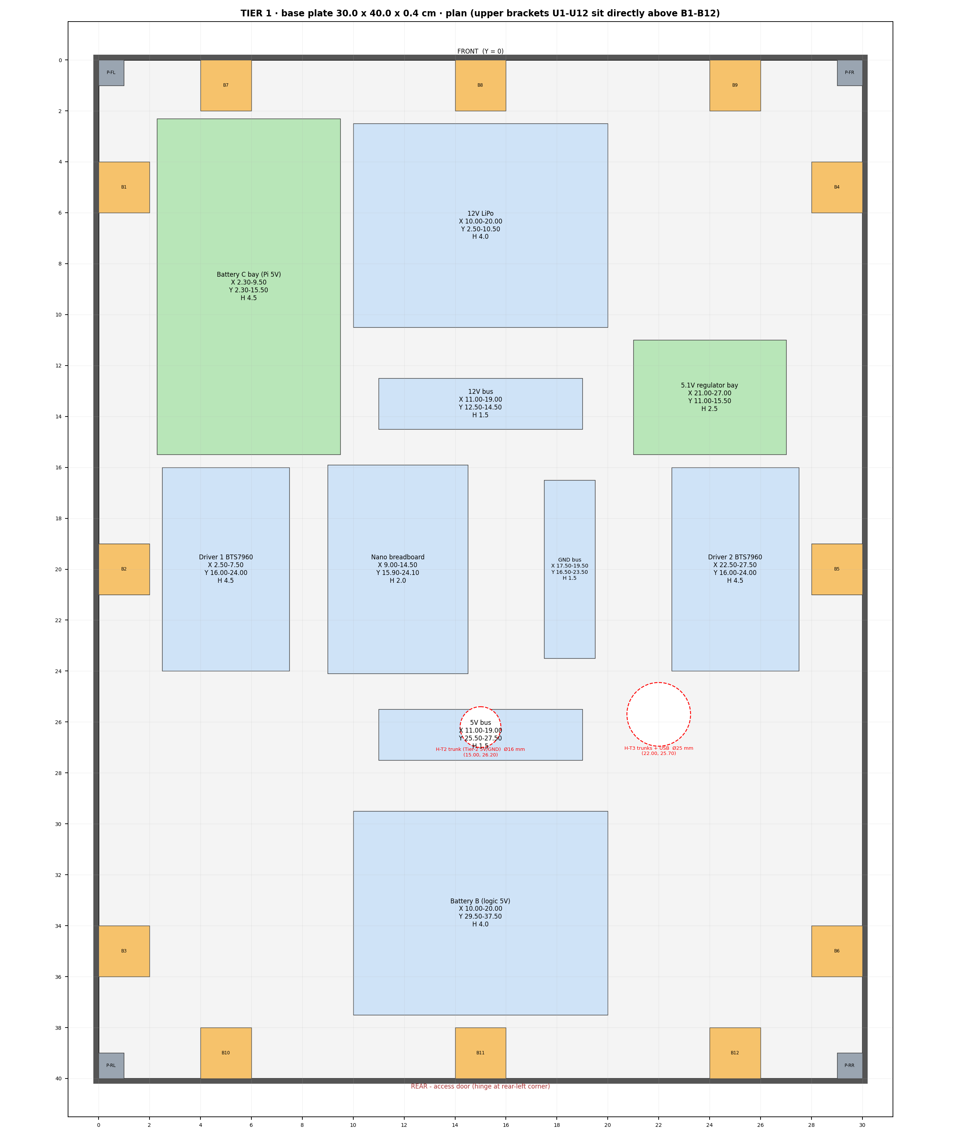
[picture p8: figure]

SIH 2026 · Team MineCrafters (ID 152475) · Mine Rescue Rover · Chassis & electronics assembly (Part 3) · all dimensions in cm unless marked | Page 4

# Sheet 4 · Tier 1 skeleton (base plate)

Dashed red circles are holes in the mid plate above (wire pass-throughs). Upper brackets U1-U12 are directly above B1-B12, bolted to the mid plate. B10-B12 / U10-U12 are door stops (not bolted to the door).

SIH 2026 · Team MineCrafters (ID 152475) · Mine Rescue Rover · Chassis & electronics assembly (Part 3) · all dimensions in cm unless marked | Page 5
Part | X from-to | Y from-to | Height
P-FL | 0.00 - 1.00 | 0.00 - 1.00 | 9.00
P-FR | 29.00 - 30.00 | 0.00 - 1.00 | 9.00
P-RL | 0.00 - 1.00 | 39.00 - 40.00 | 9.00
P-RR | 29.00 - 30.00 | 39.00 - 40.00 | 9.00
12V LiPo | 10.00 - 20.00 | 2.50 - 10.50 | 4.00
12V bus | 11.00 - 19.00 | 12.50 - 14.50 | 1.50
Driver 1 BTS7960 | 2.50 - 7.50 | 16.00 - 24.00 | 4.50
Nano breadboard | 9.00 - 14.50 | 15.90 - 24.10 | 2.00
GND bus | 17.50 - 19.50 | 16.50 - 23.50 | 1.50
Driver 2 BTS7960 | 22.50 - 27.50 | 16.00 - 24.00 | 4.50
5V bus | 11.00 - 19.00 | 25.50 - 27.50 | 1.50
Battery B (logic 5V) | 10.00 - 20.00 | 29.50 - 37.50 | 4.00
Battery C bay (Pi 5V) | 2.30 - 9.50 | 2.30 - 15.50 | 4.50
5.1V regulator bay | 21.00 - 27.00 | 11.00 - 15.50 | 2.50
Bracket | Wall | Centre along wall (cm)
B1 | Left | 5.0
B2 | Left | 20.0
B3 | Left | 35.0
B4 | Right | 5.0
B5 | Right | 20.0
B6 | Right | 35.0
B7 | Front | 5.0
B8 | Front | 15.0
B9 | Front | 25.0
B10 | Rear | 5.0
B11 | Rear | 15.0
B12 | Rear | 25.0

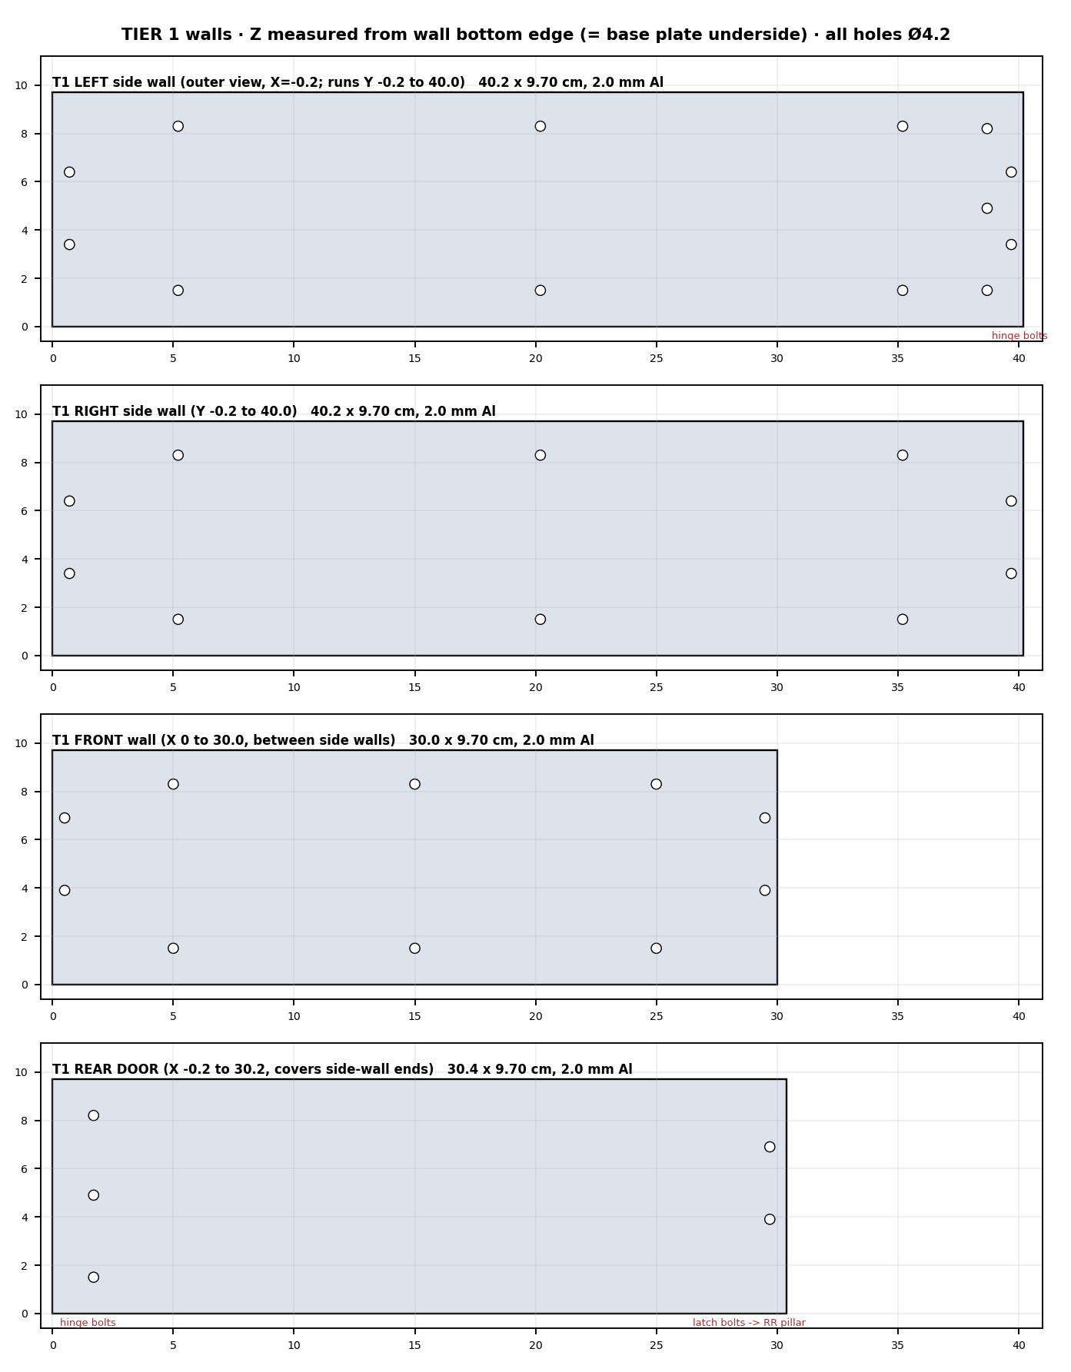
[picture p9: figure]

SIH 2026 · Team MineCrafters (ID 152475) · Mine Rescue Rover · Chassis & electronics assembly (Part 3) · all dimensions in cm unless marked | Page 6

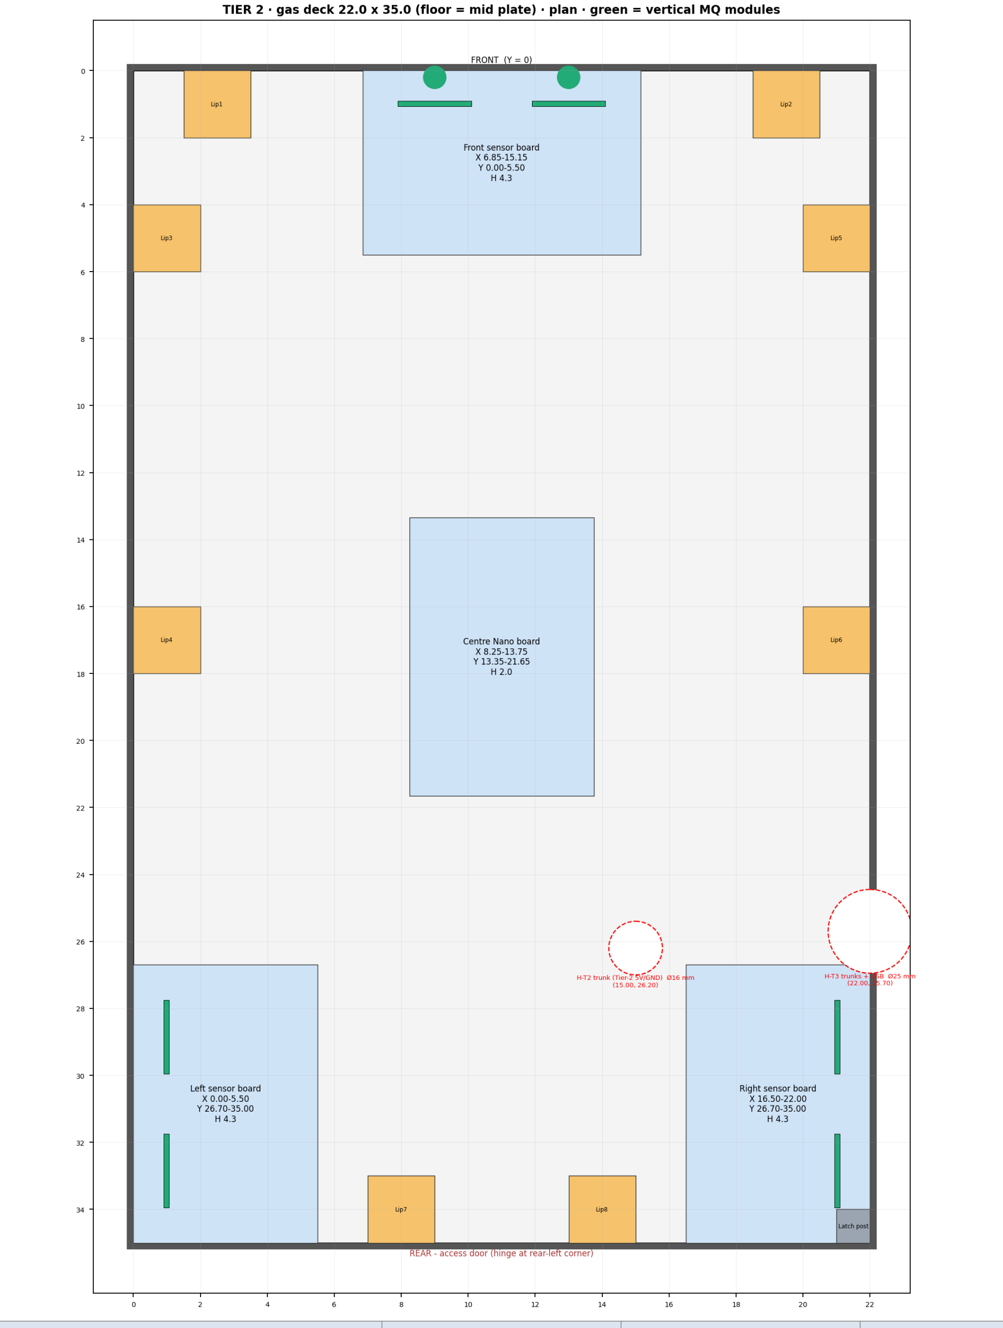
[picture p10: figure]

SIH 2026 · Team MineCrafters (ID 152475) · Mine Rescue Rover · Chassis & electronics assembly (Part 3) · all dimensions in cm unless marked | Page 7

# Sheet 5 · Tier 2 gas deck

Part | X from-to | Y from-to | Height
Front sensor board | 6.85 - 15.15 | 0.00 - 5.50 | 4.30
Centre Nano board | 8.25 - 13.75 | 13.35 - 21.65 | 2.00
Left sensor board | 0.00 - 5.50 | 26.70 - 35.00 | 4.30
Right sensor board | 16.50 - 22.00 | 26.70 - 35.00 | 4.30
Latch post | 21.00 - 22.00 | 34.00 - 35.00 | Z 4.5-9.0
Bracket | Wall | Centre along wall (cm)
Lip1 | Front | 2.5
Lip2 | Front | 19.5
Lip3 | Left | 5.0
Lip4 | Left | 17.0

SIH 2026 · Team MineCrafters (ID 152475) · Mine Rescue Rover · Chassis & electronics assembly (Part 3) · all dimensions in cm unless marked | Page 8
Bracket | Wall | Centre along wall (cm)
Lip5 | Right | 5.0
Lip6 | Right | 17.0
Lip7 | Rear | 8.0
Lip8 | Rear | 14.0

MQ modules: two per board, PCB centres at X 9.0 and 13.0 (front board) and Y 28.85 and 32.85 (side boards), plugged into the breadboard row nearest the wall with the dome facing out. The dome projects about 1.2-1.4 cm past the breadboard edge, so it pushes through the 2 mm wall into the open air. Dry-fit one module first; the open-bottom port tolerates any row.

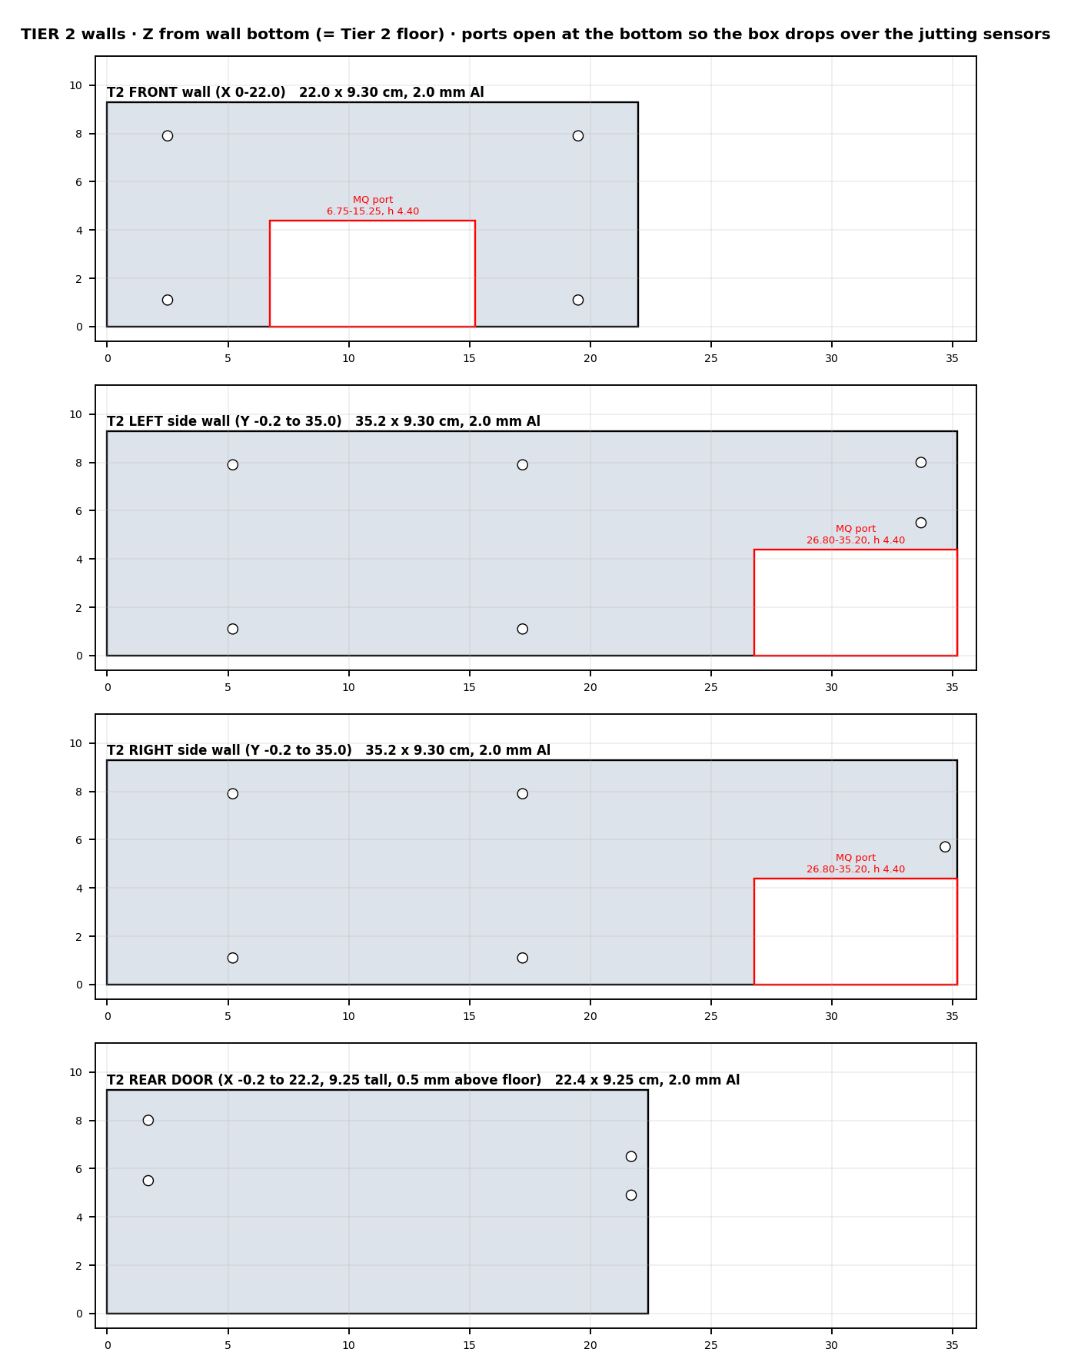
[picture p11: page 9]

SIH 2026 · Team MineCrafters (ID 152475) · Mine Rescue Rover · Chassis & electronics assembly (Part 3) · all dimensions in cm unless marked | Page 9

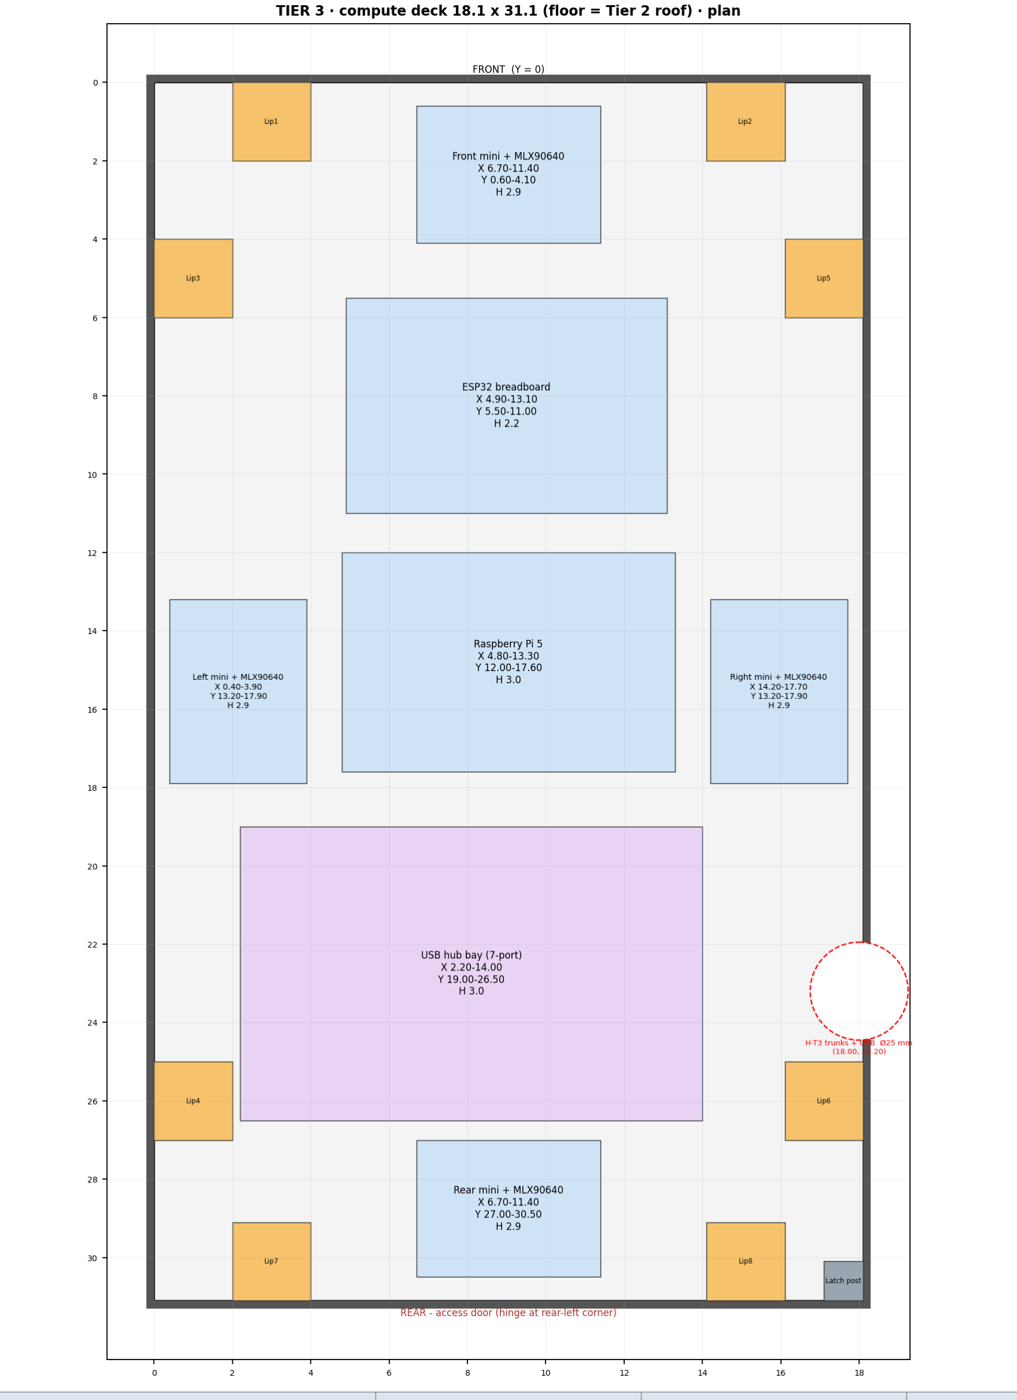
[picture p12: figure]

SIH 2026 · Team MineCrafters (ID 152475) · Mine Rescue Rover · Chassis & electronics assembly (Part 3) · all dimensions in cm unless marked | Page 10

# Sheet 6 · Tier 3 compute deck

Part | X from-to | Y from-to | Height
Front mini + MLX90640 | 6.70 - 11.40 | 0.60 - 4.10 | 2.88
Rear mini + MLX90640 | 6.70 - 11.40 | 27.00 - 30.50 | 2.88
Left mini + MLX90640 | 0.40 - 3.90 | 13.20 - 17.90 | 2.88
Right mini + MLX90640 | 14.20 - 17.70 | 13.20 - 17.90 | 2.88
ESP32 breadboard | 4.90 - 13.10 | 5.50 - 11.00 | 2.20
Raspberry Pi 5 | 4.80 - 13.30 | 12.00 - 17.60 | 3.00
USB hub bay (7-port) | 2.20 - 14.00 | 19.00 - 26.50 | 3.00
Latch post | 17.10 - 18.10 | 30.10 - 31.10 | Z 4.5-9.0
Bracket | Wall | Centre along wall (cm)
Lip1 | Front | 3.0
Lip2 | Front | 15.1
Lip3 | Left | 5.0

SIH 2026 · Team MineCrafters (ID 152475) · Mine Rescue Rover · Chassis & electronics assembly (Part 3) · all dimensions in cm unless marked | Page 11
Bracket | Wall | Centre along wall (cm)
Lip4 | Left | 26.0
Lip5 | Right | 5.0
Lip6 | Right | 26.0
Lip7 | Rear | 3.0
Lip8 | Rear | 15.1

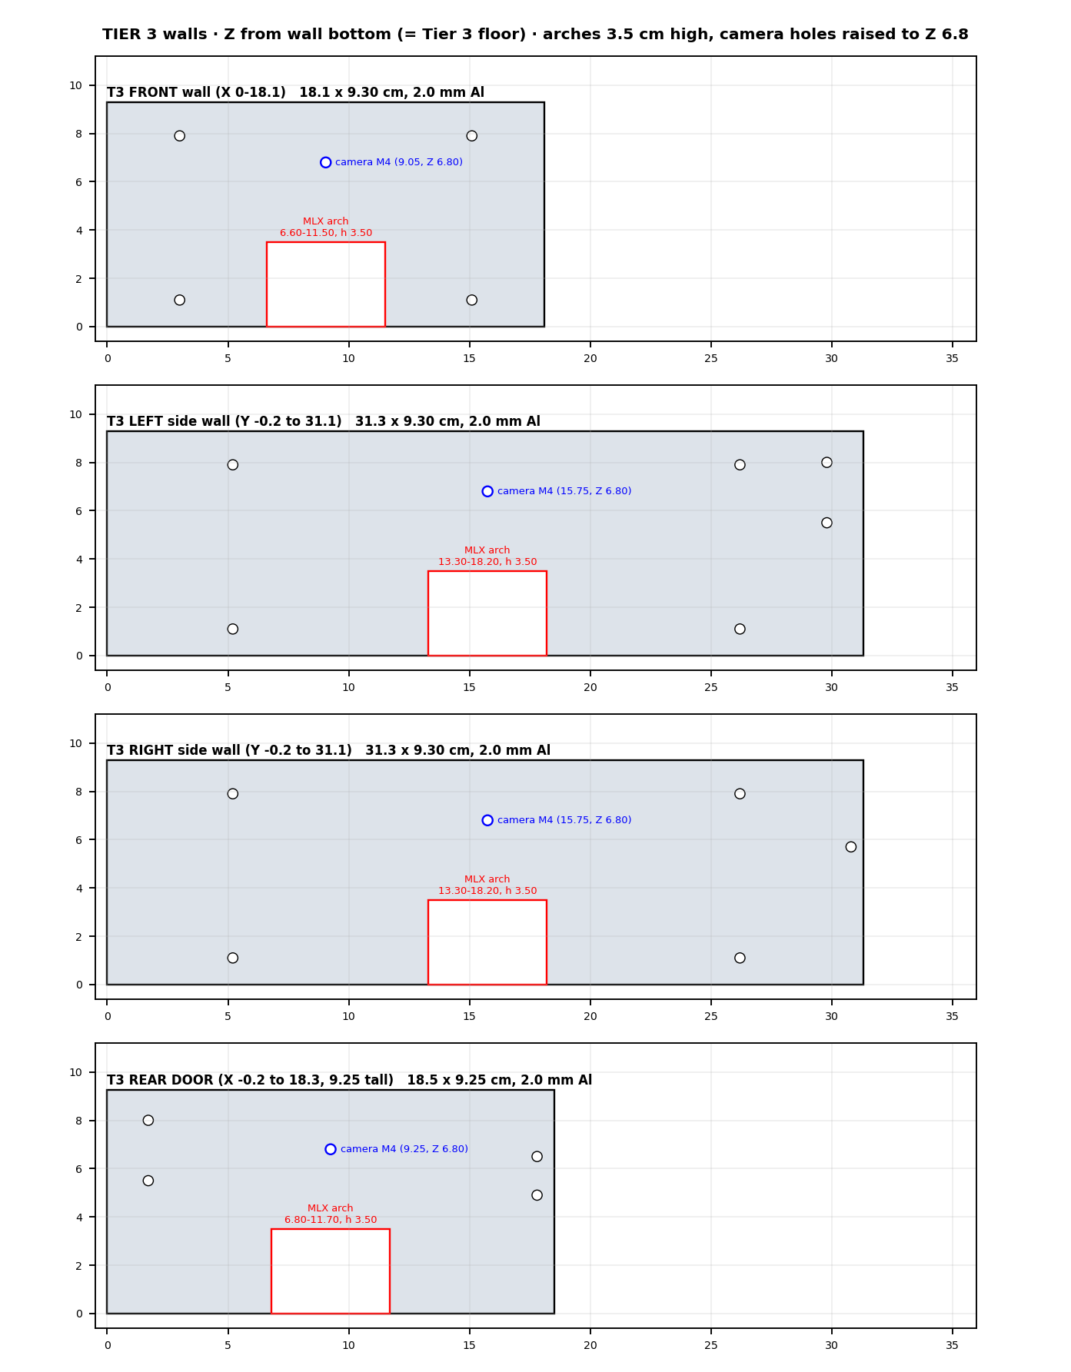
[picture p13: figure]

SIH 2026 · Team MineCrafters (ID 152475) · Mine Rescue Rover · Chassis & electronics assembly (Part 3) · all dimensions in cm unless marked | Page 12

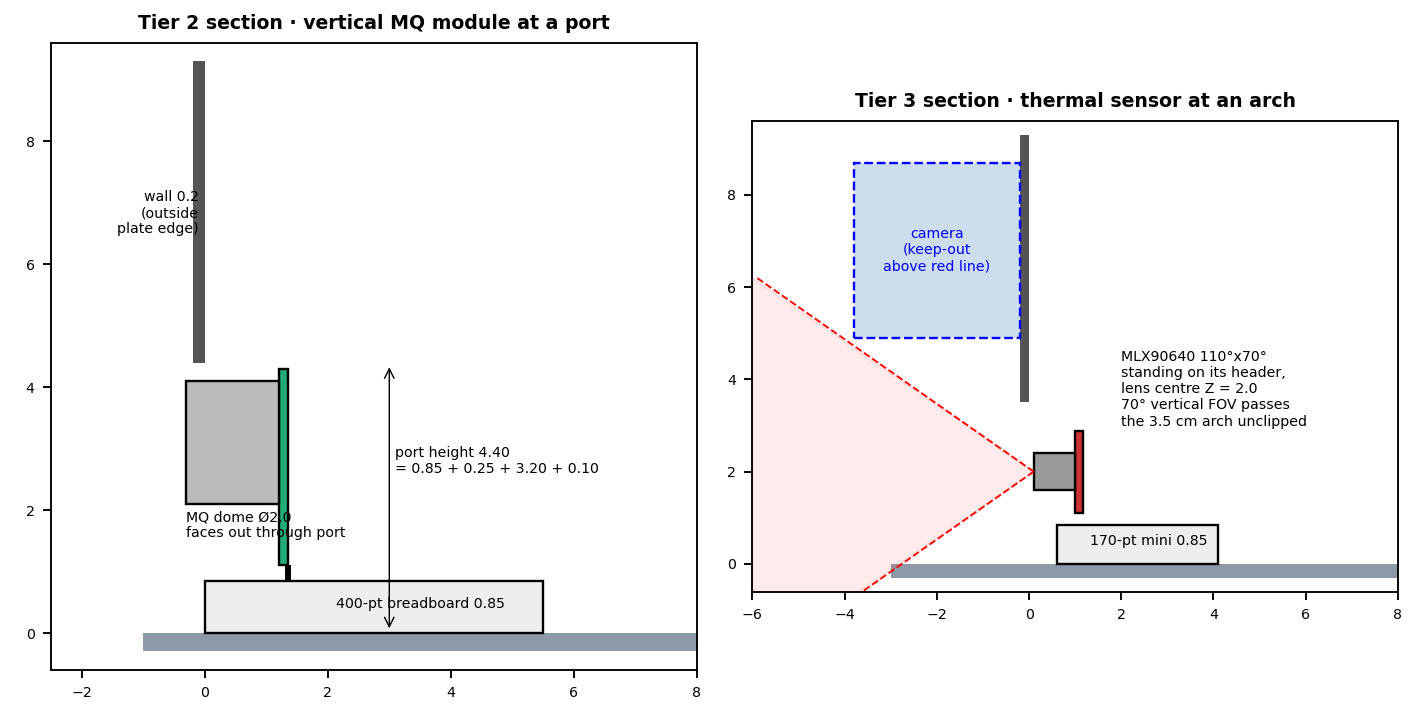
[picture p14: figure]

SIH 2026 · Team MineCrafters (ID 152475) · Mine Rescue Rover · Chassis & electronics assembly (Part 3) · all dimensions in cm unless marked | Page 13

# Sheet 7 · Roof and access doors

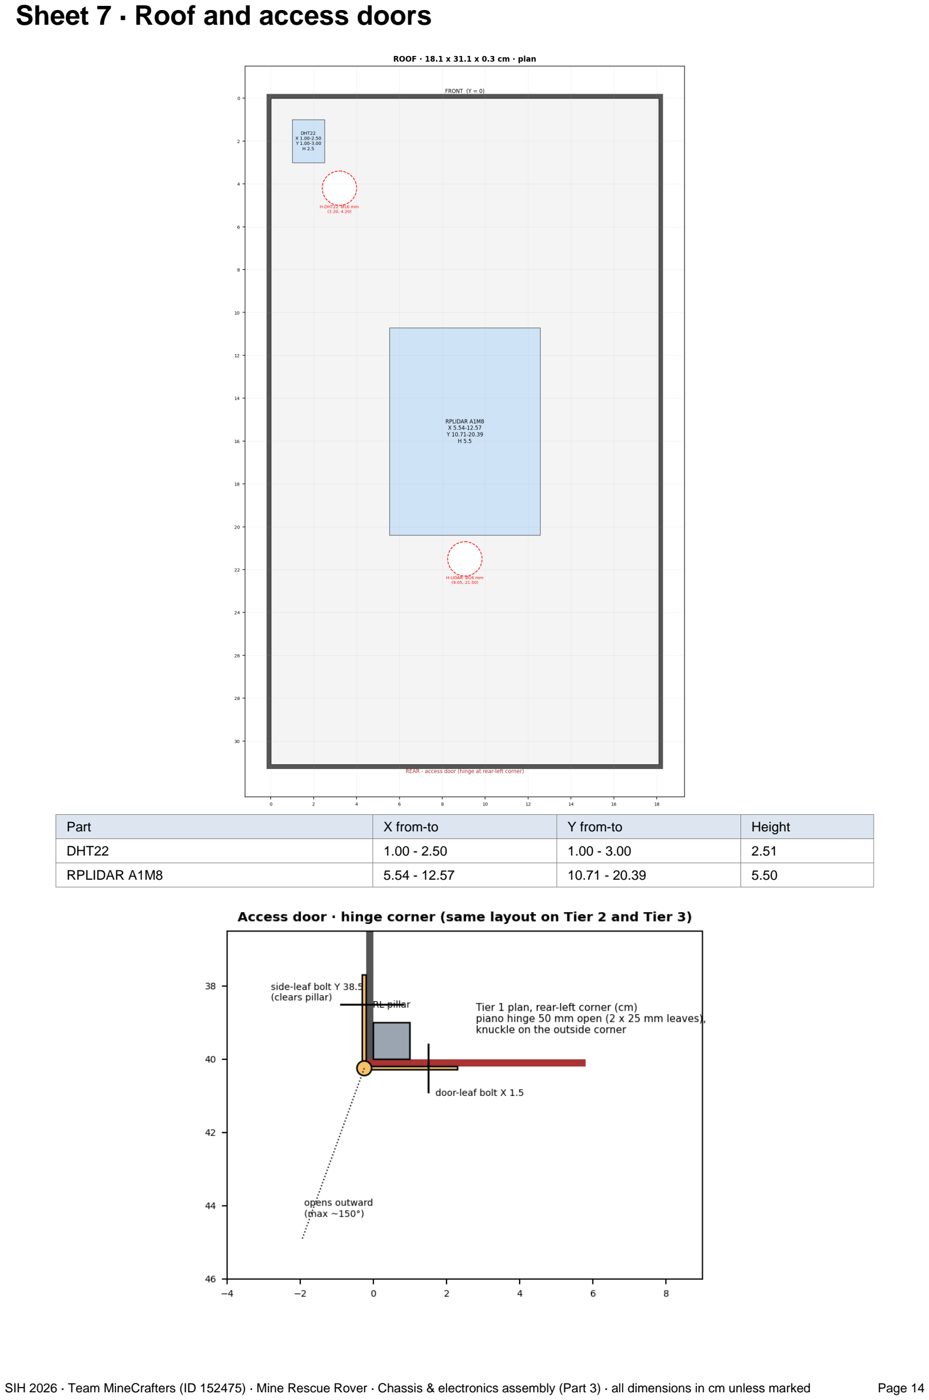
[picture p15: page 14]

SIH 2026 · Team MineCrafters (ID 152475) · Mine Rescue Rover · Chassis & electronics assembly (Part 3) · all dimensions in cm unless marked | Page 14
Part | X from-to | Y from-to | Height
DHT22 | 1.00 - 2.50 | 1.00 - 3.00 | 2.51
RPLIDAR A1M8 | 5.54 - 12.57 | 10.71 - 20.39 | 5.50

SIH 2026 · Team MineCrafters (ID 152475) · Mine Rescue Rover · Chassis & electronics assembly (Part 3) · all dimensions in cm unless marked | Page 15

Door on every tier (rear wall). Piano hinge on the outside rear-left corner: side-wall leaf bolts at 1.7 cm from the rear edge (Tier 1: Y 38.5, in front of the pillar), door-leaf bolts 1.5 cm from the corner. Tier 1 hinge 8.0 cm long, bolts at Z 1.5 / 4.9 / 8.2. Tier 2/3 hinge 4.4 cm long, starting at Z 4.8 so it stays above the gas port; bolts at Z 5.5 / 8.0. Latch: 2 x M4x20 through the door into the tapped RR pillar (Tier 1, Z 3.9 / 6.9 on the door) or the latch post (Tier 2/3, Z 4.9 / 6.5). Limit opening to about 150° on Tier 2, because the MQ-8 dome juts out of the left wall near the hinge.

SIH 2026 · Team MineCrafters (ID 152475) · Mine Rescue Rover · Chassis & electronics assembly (Part 3) · all dimensions in cm unless marked | Page 16

# Sheet 8 · Assembly sequence

### A · Machine everything flat

Cut all plates and walls (sheet 2). Drill every Ø4.2 hole from the drawings; tap pillar ends 20 mm deep; drill pillar and post through-holes; mill the gas ports and thermal arches; drill camera holes at Z 6.8. Deburr every edge (12 V bus safety).

### B · Tier 1 skeleton

1. Bolt the 4 pillars to the base plate from underneath (M4x20 into the pillar threads, Loctite blue). 2. Fit B1-B12 on the base plate, horizontal leg inward, outer face of the vertical leg flush with the plate edge; full stack with rubber washer. 3. Fit the Tier 1 components (sheet 4), Battery C bay and regulator bay. 4. Clamp the side walls and front wall against the brackets and pillars; bolt wall-to-bracket and wall-to-pillar. 5. Fit U1-U12 to the walls at the top, horizontal leg level with the pillar tops. 6. Lay the mid plate on the pillars and U-brackets; bolt into the pillars (Loctite) and the brackets (nyloc underneath), cross pattern
FL-RR-FR-RL. 7. Hang the rear door on its hinge; leave it OPEN.

### C · Tier 2

1. Stick the four breadboards to the mid plate at sheet 5 coordinates; plug in the Nano and the 6 MQ modules (vertical, domes to the walls); wire per Part 2 sheet A; run the Tier-2 trunk up through H-T2. 2. Build the box upside down: roof brackets RB1-RB8 to the Tier 2 roof, then the front and side walls, then the latch post. 3. Lower the box over the circuitry: the open-bottom ports slide past the jutting domes. 4. Fit lips Lip1-Lip8 inside, reaching in through the open rear; bolt each lip to the wall, then down through the mid plate (nyloc from inside Tier 1 through the Tier 1 door). 5. Hang the Tier 2 door; leave it open.

### D · Tier 3

1. On the Tier 2 roof: Pi 5 on its standoffs, ESP32 board, the 4 minis with MLX90640s standing on their headers, lenses facing the arch centres, and the USB hub. Run Trunk 1, Trunk 2, the Tier 1 and Tier 2 Nano USB leads up through H-T3. 2. Build the Tier 3 box the same way (roof brackets, walls, latch post); fit the cameras on their 15° brackets at the Z 6.8 holes. 3. Lower it on; check each lens looks straight out of its arch. 4. Bolt the lips (nuts inside Tier 2 through the Tier 2 door).

### E · Roof and close-up

1. Fit the RPLIDAR at dead centre (match-drill from the unit) and the DHT22 at front-left; drop their leads through H-LIDAR and H-DHT22. 2. Close the doors top-down: Tier 3, Tier 2, then Tier 1. Fit 2 latch bolts each. 3. Power-on order: 12 V and Battery B first (or together with Battery C).

## Wire routes (electrical design unchanged from Part 1 / Part 2)

Run | Path
12 V | LiPo -> 12 V bus -> both drivers B+ ; GND bus -> drivers B-. Motor leads go down through base-plate grommets (drivetrain document)
Battery B 5 V | Battery B -> 5 V bus -> Tier 1 rails. Tier-2 trunk: 5 V bus -> H-T2 -> centre Nano board rails. Trunk 1: 5 V bus -> H-T3 -> H-T3 (Tier 2 roof) -> ESP32 board
Battery C | Pack -> 5.1 V regulator (right of the 12 V bus) -> Trunk 2 (18 AWG, keep under 50 cm) -> H-T3 -> H-T3 -> Pi 5 USB-C (stripped official cable) + hub DC terminal. One GND link to the master GND bus
USB | Tier 1 Nano -> H-T3 -> Pi USB 3.0 #2; Tier 2 Nano -> H-T3 (Tier 2 roof) -> Pi USB 2.0 #2; ESP32 -> Pi USB 2.0 #1; hub -> Pi USB 3.0 #1; 4 cameras + LIDAR adapter -> hub
Roof | DHT22 3 wires -> H-DHT22 -> ESP32 3V3/GND rails + GPIO 4; LIDAR cable -> H-LIDAR -> USB adapter -> hub

SIH 2026 · Team MineCrafters (ID 152475) · Mine Rescue Rover · Chassis & electronics assembly (Part 3) · all dimensions in cm unless marked | Page 17

# Sheet 9 · Verification and checks before cutting metal

Script checks over the single coordinate model: every part inside its deck; no two parts overlap in 3D; no pass-through hole under a part; no lip bolt tip hits a part in the deck below; no bracket inside a sensor port; thermal field of view through the arches; M4x20 length at every joint type.
Result
MLX FOV: needs 2.90 cm high x 3.26 cm wide, arch 3.5 x 4.9 -> OK
Camera hole Z=6.80 cm: with a 3.8 cm tall camera, bottom at 4.90 cm clears the MLX FOV for up to 3.9 cm protrusion Stack Plate 0.3 + bracket 0.2 protrusion past nyloc 0.82 cm OK
Stack Base 0.4 + bracket 0.2 protrusion past nyloc 0.72 cm OK
Stack Wall 0.2 + bracket 0.2 protrusion past nyloc 0.92 cm OK
Stack Wall 0.2 + pillar 1.0 (through) protrusion past nyloc 0.14 cm OK Stack Hinge leaf 0.1 + wall 0.2 protrusion past nyloc 1.04 cm OK Pillar tap engagement, base 0.4: 1.52 cm (tap depth 2.0) -> OK
TOTAL ERRORS: 0

## Things you must confirm on the real parts

# | Check

1 | USB-HUB-7U outline fits the 11.8 x 7.5 x 3.0 cm bay (Waveshare gives it only as a drawing image).
2 | Battery C pack case <= 13.0 x 7.0 x 4.5 cm and the regulator <= 6.0 x 4.5 x 2.5 cm; regulator rated >= 8 A at 5.1 V.
3 | Your MQ header lets the module stand vertical (straight in-plane or 90° header). Dry-fit one module at a port.
4 | MLX90640 lens centre sits about 2.0 cm above the deck when standing on its header; the arch allows 2.9 cm at worst case.
5 | Camera body: its underside must stay above the red line on the section drawing (at most 3.9 cm protrusion with a 3.8 cm tall camera at Z 6.8).
6 | BTS7960 and bus-bar hole patterns: match-drill from your actual boards; their footprints are as in your layout.

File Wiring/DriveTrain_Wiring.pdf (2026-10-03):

# SIH 2026 Rover · Tier 1 Drivetrain Wiring

Part 1 of 6 · Tier 1 · 2× BTS7960 · 4× NFP-36GP-555-EN geared motors with built-in hall encoders (Part 4) · Arduino Nano V3 (CH340) closes the speed loop and streams odometry to the Pi 5

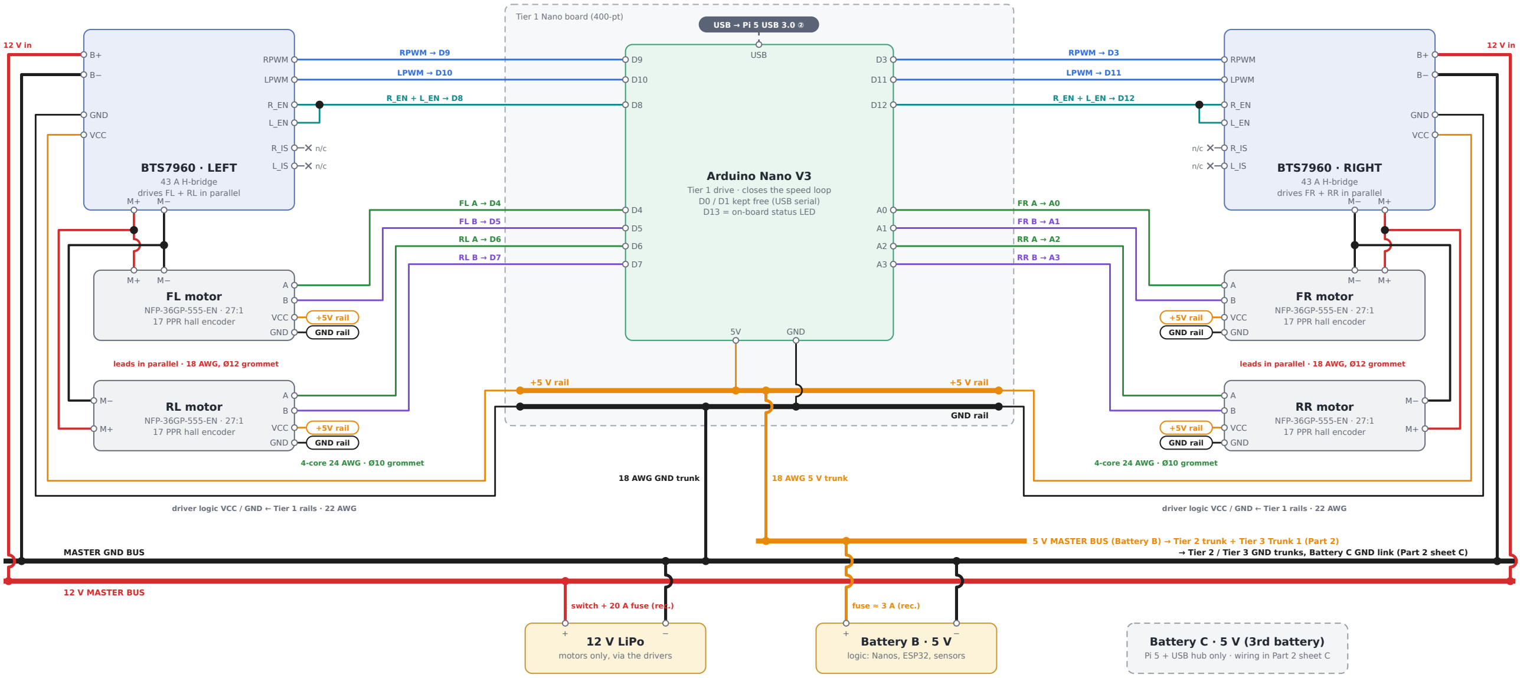
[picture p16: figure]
BTS7960 · LEFT; 43 A H-bridge drives FL + RL in parallel; FL motor; NFP-36GP-555-EN · 27:1 17 PPR hall encoder; RL motor; BTS7960 · RIGHT; 43 A H-bridge drives FR + RR in parallel; FR motor; RR motor; Arduino Nano V3; Tier 1 drive · closes the speed loop D0 / D1 kept free (USB serial) D13 = on-board status LED; 12 V LiPo; motors only, via the drivers; Battery B · 5 V; logic: Nanos, ESP32, sensors; Battery C · 5 V (3rd battery); Tier 1 Nano board (400-pt); +5V rail; GND rail; GND; VCC; RPWM; LPWM; USB; USB → Pi 5 USB 3.0 ②; RPWM → D9; LPWM → D10; leads in parallel · 18 AWG, Ø12 grommet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

Pi 5 + USB hub only · wiring in Part 2 sheet C driver logic VCC / GND ← Tier 1 rails · 22 AWG

driver logic VCC / GND ← Tier 1 rails · 22 AWG

### 5 V MASTER BUS (Battery B) → Tier 2 trunk + Tier 3 Trunk 1 (Part 2)

→ Tier 2 / Tier 3 GND trunks, Battery C GND link (Part 2 sheet C)

switch + 20 A fuse (rec.) | fuse ≈ 3 A (rec.)

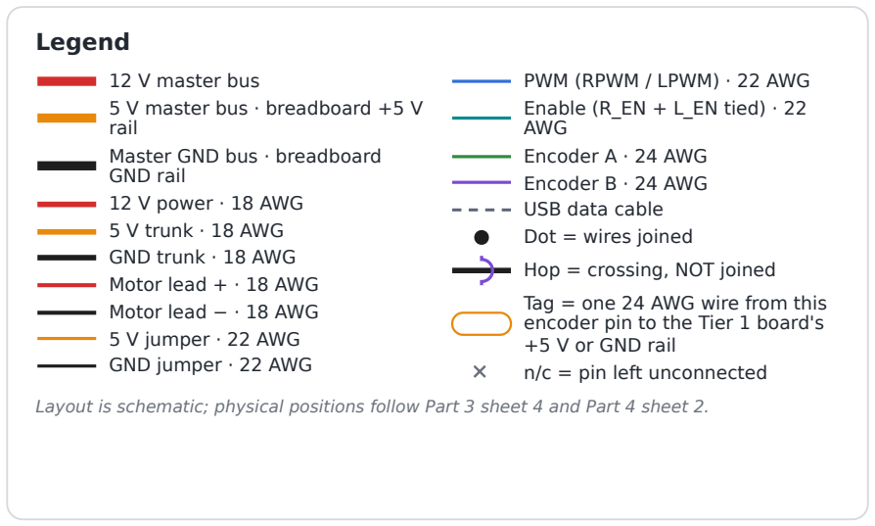
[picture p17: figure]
Legend; 12 V master bus 5 V master bus · breadboard +5 V rail Master GND bus · breadboard GND rail 12 V power · 18 AWG 5 V trunk · 18 AWG GND trunk · 18 AWG Motor lead + · 18 AWG Motor lead − · 18 AWG 5 V jumper · 22 AWG GND jumper · 22 AWG; PWM (RPWM / LPWM) · 22 AWG Enable (R_EN + L_EN tied) · 22 AWG Encoder A · 24 AWG Encoder B · 24 AWG USB data cable Dot = wires joined; Hop = crossing, NOT joined; Tag = one 24 AWG wire from this encoder pin to the Tier 1 board's +5 V or GND rail n/c = pin left unconnected

Layout is schematic; physical positions follow Part 3 sheet 4 and Part 4 sheet 2.

### Tier 1 Nano pin map

D9 / D10 | LEFT BTS7960 RPWM / LPWM · Timer1 PWM, 3.92 kHz
D8 | LEFT R_EN + L_EN (tied) · HIGH = enabled, LOW while booting
D3 / D11 | RIGHT BTS7960 RPWM / LPWM · Timer2 PWM, 3.92 kHz
D12 | RIGHT R_EN + L_EN (tied)
D4 / D5 | FL encoder A / B · port D pin-change interrupt
D6 / D7 | RL encoder A / B · port D pin-change interrupt
A0 / A1 | FR encoder A / B · port C pin-change interrupt
A2 / A3 | RR encoder A / B · port C pin-change interrupt
D13 | On-board LED · slow blink run · solid wait for Pi · fast blink fault
5V, GND | Tier 1 rails · never VIN
USB (D0/D1) Pi 5 USB 3.0 ② · 115200 baud

Spare: D2, A4, A5, A6, A7. Encoder pins are fixed (the interrupt code reads whole ports); PWM must stay on D3 / D9 / D10 / D11.

### Build notes

1. Motor 6-pin plug (JST XH2.54): split it at the motor. M+ / M− go to the driver on 18 AWG through the Ø12 grommets; the four encoder wires (VCC, GND, A, B) go to the Tier 1 Nano board on 4-core 24 AWG through the Ø10 grommets at (150, 65) and (150, 335).
2. Encoder VCC takes 3.3–5 V only: take it from the +5 V rail, never from 12 V. Read the wire order off the motor label or datasheet before plugging in.
3. Keep each encoder's four wires together and away from the motor leads and PWM wires. Label FL / RL / FR / RR at both ends; heat-shrink every joint.
4. The encoders have their own pull-ups, so A / B swing 0–5 V straight into the Nano. No extra resistors.
5. R_IS / L_IS stay unconnected: stalls are detected from the encoders. R_EN and L_EN are tied on each driver.
6. Do not swap M+ / M− to fix direction: the bring-up check (Part 4, sheet 8, step 3) stores the motor and encoder signs in the Nano.
7. Switch 12 V and Battery B on before (or with) the Pi, so the Pi does not back-feed the Nano, the drivers' logic and the encoders over USB.
8. The rover has three batteries. Only the 12 V LiPo and Battery B feed Tier 1; Battery C powers only the Pi 5 and the USB hub; its wiring, including its single GND link to the master GND bus, is on Part 2 sheet C.
Checked by script: 44 connections · 10 hops · 0 errors. Encoder wiring per Part 4 sheet 8.
SIH 2026 · Team MineCrafters (ID 152475) · Mine Rescue Rover | Part 1 · Tier 1 drivetrain wiring (with encoders) | Page 1 of 1

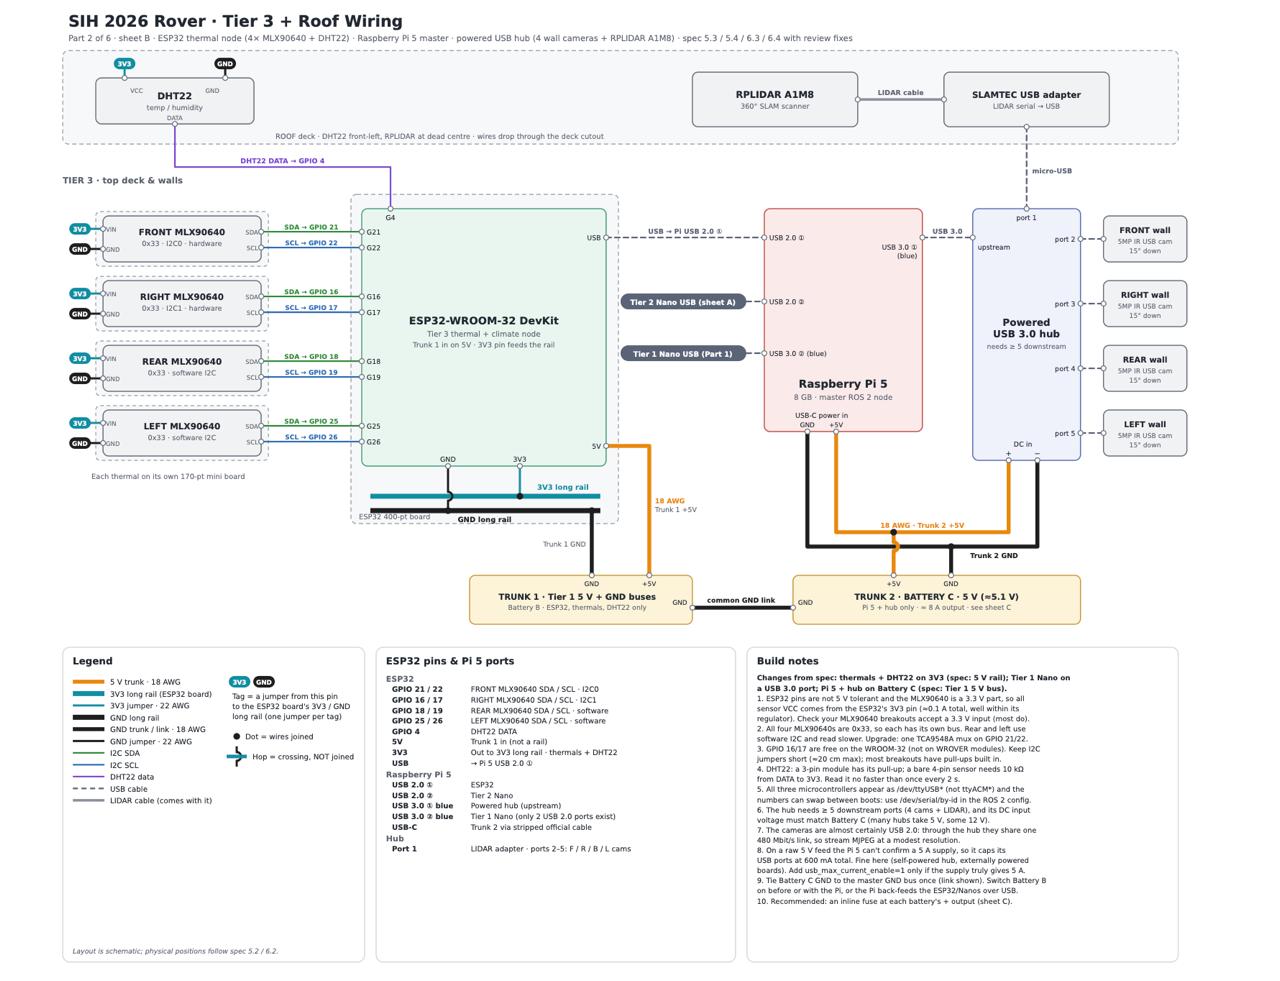
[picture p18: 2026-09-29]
Wiring/Tier3_wiring.png

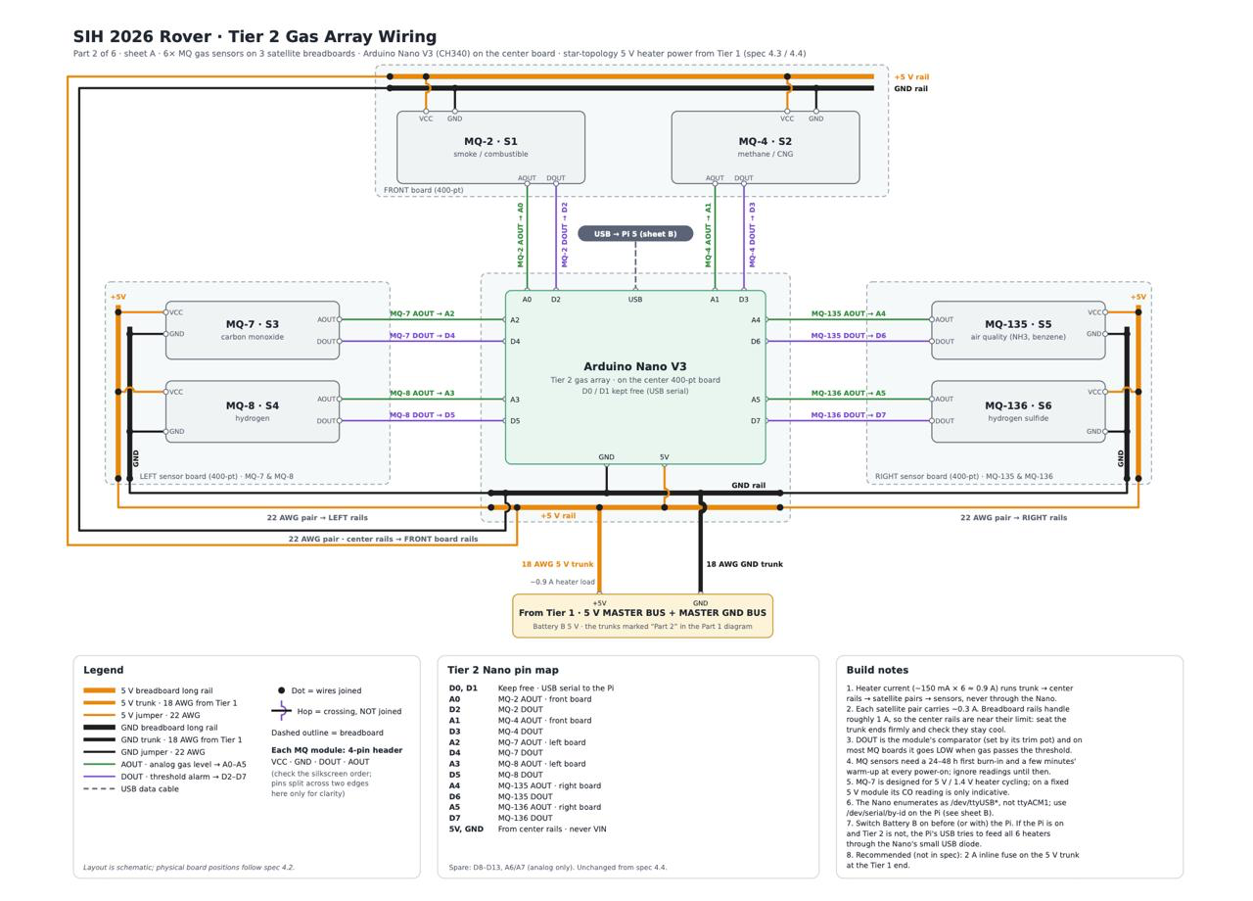
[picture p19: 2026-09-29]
Wiring/gas_arr_wiring.png
